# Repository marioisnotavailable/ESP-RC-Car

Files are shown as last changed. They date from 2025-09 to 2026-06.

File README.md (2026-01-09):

# ESP-RC-Car

A self-engineered, open-source drift car powered by an ESP32-S3 microcontroller, designed for a school project. This project integrates robust battery management features, a high-performance mini brushless motor, and a custom phone app controller.

---

## Features

- **ESP32-S3 MCU:** Efficient, reliable microcontroller for all car logic and communication
- **USB Power Delivery & Battery Management:**  
  - Includes Battery Management System (BMS), charging IC, and balancing ICs for battery protection and health
- **Mini1410 2500kv Motor:**  
  - Driven by DRV8323SRTAR motor driver
- **Custom Controller App:**  
  - Written in Flutter, communicates with the car via WebSocket
  - Source code and Android/iOS builds in [`App/final_build`](./App/final_build)
- **PCB Design:**  
  - Schematics and PCB layout created in Altium, available in the repo
- **Firmware:**  
  - PlatformIO based, located in the repo

---

## Hardware Requirements

- ESP32-S3 microcontroller
- Mini1410 2500kv brushless motor
- DRV8323SRTAR motor driver
- USB PD hardware (for charging)
- Battery pack with BMS, charging, and balancing ICs
- Chassis (3D print file provided; other car body prints must be purchased separately)
- Additional electronics (as defined in PCB files)

---

## Getting Started

### Clone the Repo

```bash
git clone https://github.com/marioisnotavailable/ESP-RC-Car.git
```

### Firmware

- Code for the ESP32-S3 is organized for PlatformIO.  
- Configure and build per PlatformIO requirements.

### Controller App

- Find source and builds under [`App/final_build`](./App/final_build)
- Flutter-based; can build for Android or iOS as needed

---

## PCB & Schematics

- All Altium files (schematics and board) are included for public use.

---

## 3D Prints

- Chassis STL provided in this repo
- All other 3D printable parts must be purchased

---

## License

Open source; no specific license chosen at this time.

---

## Media

**[Demo Image Placeholder]**  
*Insert image or GIF of assembled car here*  
**[Demo Video Placeholder]**  
*Insert video or link to demonstration here*

---

## Contributing

Pull requests welcome! If you have ideas for improvements or new features, feel free to submit.

---

## Acknowledgments

This project is open to the community—no personal or institutional credits required.

---

```
**Please update this README with build instructions, usage notes, or troubleshooting tips as the project evolves!**
```

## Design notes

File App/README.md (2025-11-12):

# ESP-RC Car Controller

This is the companion Flutter application for the ESP32-based RC car project. It provides a real-time, low-latency interface to control the car's throttle and steering over a WebSocket connection.

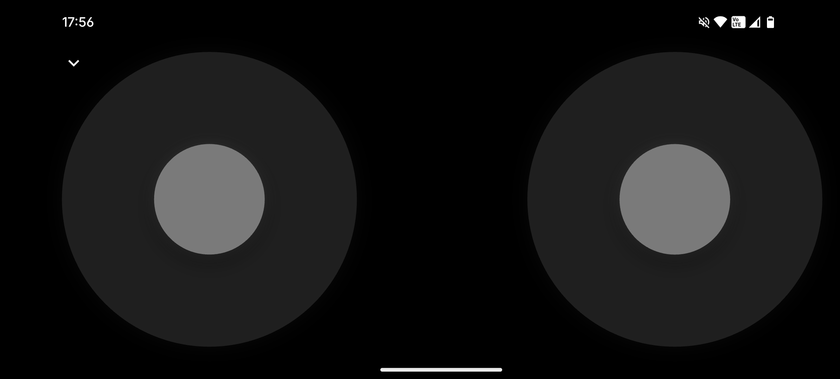
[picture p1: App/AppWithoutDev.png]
App Screenshot


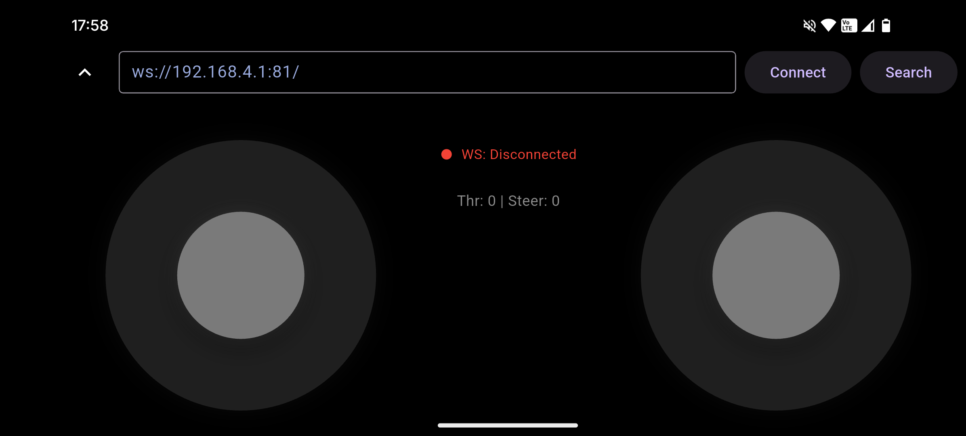
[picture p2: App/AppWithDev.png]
Developer Panel Screenshot


## Features

- **Real-time Control**: Low-latency vehicle control via a WebSocket interface.
- **Dual Control Modes**:
    - Responsive on-screen joysticks for touch-based control.
    - Full support for physical gamepads on both Android and iOS.
- **Automatic Discovery**: The app automatically finds the car on your local network.
    - **UDP Broadcast**: The primary method for quick discovery.
    - **TCP Subnet Scan**: A fallback that scans the entire local network to find the car.
- **Resilient Connectivity**: Automatically reconnects if the connection is lost.
- **Clean UI**: A simple, dark-themed interface that focuses on the driving experience.

## How to Control the Car

### On-Screen Controls
When no gamepad is connected, two virtual joysticks will be visible:

- **Left Joystick (Vertical)**: Controls Throttle (Forward/Reverse).
- **Right Joystick (Horizontal)**: Controls Steering (Left/Right).

### Physical Gamepad
Connect a standard Bluetooth or USB gamepad to your phone for a more tactile experience. The app will automatically detect it.

- **Left Stick (X-Axis)**: Steering
- **Right Trigger (R2/RT)**: Throttle (Forward)
- **Left Trigger (L2/LT)**: Brake / Reverse

## Connection Methods

The app is designed to connect to the ESP32 with minimal effort. It tries the following methods in order:

1.  **UDP Discovery**: On startup, the app sends a broadcast message over the network. The ESP32 is expected to respond with its IP address.
2.  **TCP Scan**: If UDP discovery fails, the app identifies your phone's local subnet (e.g., `192.168.1.0/24`) and scans every host on that network to find the car's WebSocket port.
3.  **Default Fallback**: If both discovery methods fail, it attempts to connect to `ws://192.168.4.1:81/`. This is the default address for when the ESP32 is running in its own Wi-Fi Access Point (AP) mode.
4.  **Manual Connection**: You can tap the "expand" icon at the top of the screen to open the developer panel, where you can manually enter a WebSocket URL and connect.

## Technology Stack

- **Framework**: Flutter
- **Connectivity**: `dart:io` for WebSockets, UDP Sockets, and TCP Sockets.
- **State Management**: `provider` with `ChangeNotifier`.
- **Native Integration**:
    - **Android (Kotlin)**: Uses `InputManager` to listen for native gamepad events.
    - **iOS (Swift)**: Uses the `GameController` framework to listen for native gamepad events.

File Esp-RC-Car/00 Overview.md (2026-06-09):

---
tags: [moc, esp-rc-car, diplomarbeit]
---

# ESP-RC-Car

Diplomarbeitsprojekt **HTL St. Pölten**, 4BHELS — Mario Haunold & Leon Dillinger.
Ferngesteuertes Elektrofahrzeug mit eigenentwickelter Platine, BLDC-Antrieb über DRV8323S, WiFi-WebSocket-Steuerung über eine Flutter-App und vollständigem Energiemanagement (USB-PD-Laden, 2S-LiPo, Zellbalancer).

## Kontext

- Schuljahr 2025/26 — Planung Sept. 2025, erste Platine bestellt/getestet Dez. 2025, überarbeitete Platine ab März 2026
- Abgabedatum 29.5.2026, Lehrer RZEP
- Eigene Mehrlagen-PCB in Altium Designer, eigene Firmware (PlatformIO/ESP-IDF), eigene App (Flutter/Dart)

## Inspiration

Mechanische Grundlage: Open-Source-Projekt [Build a 3D Printed Arduino RC Drift Car](https://www.instructables.com/Build-a-3D-Printed-Arduino-RC-Drift-Car-With-Smoke/) (Instructables). Übernommen: Allrad-Antriebsstrang mit Differential, Radaufhängung, Servo-Lenkmechanik. Neu entwickelt: das gesamte Chassis (an die eigene Platine angepasst) sowie die komplette Elektronik und Steuersoftware.

## Themen-Notizen

- [[Firmware Overview|Firmware]] — ESP32-S3, ESP-IDF, FreeRTOS-Tasks, BLDC-Kommutierung, Safe Mode
- [[PCB|Hardware / PCB]] — Schaltplan, ICs, MOSFETs, erste/zweite Platinen-Version
- [[Motor & Treiber]] — Mini1410 BLDC + DRV8323S Gate-Treiber
- [[App Overview|Flutter App]] — WebSocket-Steuerung, Joystick, Gamepad, Discovery, Batterieanzeige
- [[3D-Druck]] — Chassis-Iterationen, Restmechanik aus Referenzprojekt

## Kern-Stack

| Bereich | Technologie |
|---|---|
| MCU | ESP32-S3-WROOM-1-N8 (8 MB Flash) |
| Firmware | C++ / PlatformIO / ESP-IDF |
| Motor | BLDC Mini1410 2500 kV |
| Gate-Treiber | DRV8323SRTAR (SPI, 6 PWM) |
| Leistungsstufe | 6× IPD047N03LF2 (30 V N-Ch) |
| Energie | USB-PD via STUSB4500 + MP2615 Lader + 2S LiPo |
| Schutz | S-82B2 (Primärschutz) + BQ29200 (Balancing) |
| Power-Pfad | TPS2121 Power-Mux + LMR51430 3,3 V Buck |
| App | Flutter (Android/iOS/Windows), WebSocket + UDP-Discovery |

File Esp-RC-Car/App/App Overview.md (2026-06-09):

---
tags: [app, flutter, dart, esp-rc-car]
---

# Flutter App — Übersicht

Cross-platform Controller-App für das [[ESP-RC-Car]], geschrieben in **Flutter/Dart**. Steuert das Fahrzeug per WiFi-WebSocket in Echtzeit, zeigt die Batteriespannung an und erlaubt die Server-Suche im lokalen WLAN.

## Plattformen

- Android (Release-APK: `App/final_build/EspRCCar.apk`)
- iOS (CocoaPods-Integration, IPA: `App/final_build/EspRCCar.ipa`)
- Windows (nativer Gamepad-Support via `gamepad_channel.cpp`)
- macOS, Linux, Web (Flutter-Standard)

## Architektur

```
main.dart
├── MultiProvider
│   ├── ConnectionService    ← WebSocket + UDP/TCP-Discovery
│   └── ControllerService    ← Gamepad/Joystick → Steuerbefehle
└── RCCarApp
    ├── ui/dev_panel.dart      ← DevPanel (Diagnose + Update)
    ├── ui/gamepad_status.dart ← Gamepad-Verbindungsanzeige
    └── widgets/joystick.dart  ← Touch-Joystick-Widget

update_service.dart            ← GitHub-Release Self-Update (Android)
```

State-Management über das `provider`-Package; sowohl `ConnectionService` als auch `ControllerService` sind `ChangeNotifier`.

## UI-Ausrichtung

App startet immer im **Landscape-Modus**:

```dart
SystemChrome.setPreferredOrientations([
  DeviceOrientation.landscapeLeft,
  DeviceOrientation.landscapeRight,
])
```

## Steuerung

- Virtueller Joystick mit konfigurierbarer Empfindlichkeit / Totzone und Skalierungsfunktion (gegen Zittern)
- Physischer Gamepad-Controller als Alternative (Bluetooth/USB)
- 50 Hz Sendeloop mit EMA-Tiefpassfilterung
- Übertragung über WebSocket: Throttle/Steer/Flags als JSON oder Rohwerte

## Server-Discovery

1. Standardmäßig **UDP-Broadcast-Discovery** auf dem lokalen Netz → Fahrzeug antwortet mit seinem WebSocket-Endpunkt
2. Fallback: **TCP-Subnet-Scan** falls UDP blockiert wird
3. Zuletzt verwendete URL wird in `SharedPreferences` persistiert (Standard im Soft-AP-Modus: `ws://192.168.4.1:81/`)
4. Manuelle URL-Eingabe im DevPanel

## Batterieanzeige

Echtzeit-Anzeige der 2S-LiPo-Spannung mit prozentualer Restkapazität, Farbcode und Icon. Der Wert kommt aus dem `batt_queue` der Firmware und wird über WebSocket gepusht.

## DevPanel

- Verbindungsstatus, Latenz, empfangene Sensordaten
- Manuelle WebSocket-URL
- ⟳-Update-Button (nur Android)

## In-App-Update (Android)

- `update_service.dart` liest `releases/latest` über die GitHub-Releases-API, vergleicht mit der installierten Version (`package_info_plus`)
- Bei neuer Version: APK herunterladen (`http` + `path_provider`), Installer öffnen (`open_filex`)
- Voraussetzung: alle Releases mit demselben Signing-Key
- App-Version kommt im CI aus dem Release-Tag (`flutter build --build-name`)

## Bibliotheken

| Paket | Zweck |
|---|---|
| `web_socket_channel` | WebSocket zur ESP32-Firmware |
| `flutter_joystick` | virtueller Joystick |
| `gamepad` | physischer Controller |
| `shared_preferences` | Server-URL persistieren |
| `provider` | State-Management |
| `package_info_plus` / `http` / `path_provider` / `open_filex` | Self-Update |

## Module

- [[ConnectionService]] — WebSocket + UDP/TCP-Discovery
- [[ControllerService]] — Gamepad/Joystick-Steuerlogik
- [[UpdateService]] — GitHub-Release Self-Update (Android)

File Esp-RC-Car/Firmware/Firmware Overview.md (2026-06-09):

---
tags: [firmware, esp32, espidf, freertos, esp-rc-car]
---

# Firmware Overview

PlatformIO-Projekt auf **ESP-IDF**, Ziel: **ESP32-S3-WROOM-1-N8** (8 MB Flash). Hauptaufgaben: BLDC-Motoransteuerung, WiFi/WebSocket-Server, Servo-Lenkung, ADC-Batteriemessung, USB-PD-Konfiguration, OTA-Update, Crash-Recovery / Safe Mode.

Siehe auch: [[ESP-RC-Car|Projekt-Übersicht]], [[PCB]], [[Motor & Treiber]].

## Build-Environments

| Environment | Beschreibung |
|---|---|
| `espidf` | Hauptfirmware (USB Serial Upload) |
| `espidf_ota` | OTA-Upload via `esp-rc-car.local` |
| `espidf_factory` | Factory-Recovery-Firmware |

OTA-Passwort: `esprccar`.

## Projektstruktur

```
Code/
├── platformio.ini       framework = espidf
├── sdkconfig.defaults   ESP-IDF Konfiguration
├── partitions.csv       Flash-Partitionierung
├── src/main.c           app_main: Init + 4 Tasks spawnen
└── components/
    ├── rc_common/       Shared: Cmd, Queues, EventGroup, Pins
    ├── rc_motor/        motor_task + DRV8323 SPI
    ├── rc_comms/        comms_task: WiFi, WebSocket, UDP
    ├── rc_system/       system_task: ADC, NVS, Recovery, Servo
    └── rc_bg/           bg_task: FOTA, Serial Console
```

## Flash & Partitionen

- 16 MB QIO-OPI Flash
- Filesystem: **LittleFS** (Partition-Label `littlefs`, Mount `/littlefs`)
- Partitions: `partitions.csv` (custom, inkl. zwei OTA-App-Slots + Factory)

## sdkconfig Highlights

- CPU: 240 MHz
- FreeRTOS: 1000 Hz Tick
- Task-Watchdog: 10 s Timeout
- WebSocket-Support: aktiviert
- SPIRAM: aktiv im **OCT-Modus** (Board hat OPI-PSRAM)
- OTA-Rollback: `CONFIG_BOOTLOADER_APP_ROLLBACK_ENABLE=y`

## FreeRTOS Task-Architektur

```
app_main()
  nvs_flash_init() → esp_netif_init() → rc_common_init()
  rc_recovery_check() → rc_settings_load()
  │
  ├── motor_task   Prio 10  4 KB  BLDC Kommutierung + DRV8323
  ├── comms_task   Prio 7   8 KB  WiFi + WebSocket + UDP
  ├── system_task  Prio 5   6 KB  ADC + Settings + Recovery + Servo
  └── bg_task      Prio 2   6 KB  FOTA + Serial Console
```

### Inter-Task-Kommunikation

```
comms_task  → xQueueOverwrite(cmd_queue)  → motor_task
system_task → xQueueOverwrite(batt_queue) → comms_task (broadcast)

rc_events (EventGroup):
  BIT0: WIFI_CONNECTED_BIT
  BIT1: SAFE_MODE_BIT     → motor_task suspendiert sich
  BIT2: MOTOR_FAULT_BIT   → DRV8323 Fault erkannt
```

## WiFi & Konfiguration

Beim Boot versucht der ESP32-S3 sich mit einem in NVS gespeicherten WLAN zu verbinden. Wird kein bekanntes Netzwerk gefunden, startet er einen **Soft-AP** mit eingebettetem Webserver, über den per Browser SSID/Passwort hinterlegt werden können. Nach Neustart verbindet sich der MCU mit dem konfigurierten Netzwerk und betreibt dort den WebSocket-Server für die Steuerung. Der AP dient ausschließlich der Konfiguration — die Fahrzeugsteuerung läuft nur im gemeinsamen WLAN.

Discovery: Der ESP32-S3 sendet einen UDP-Beacon mit seinem WebSocket-Endpunkt; die App findet ihn darüber automatisch, als Fallback per TCP-Subnet-Scan.

## BLDC-Kommutierung

- Gate-Treiber: **DRV8323SRTAR** (TI) über dedizierten SPI-Bus
- 6 PWM-Kanäle via **LEDC** für die 3-Phasen-Vollbrücke (INH_A/B/C high-side, INL_A/B/C low-side)
- 6-Step-Trapezoid-Kommutierung mit Ramp-Up
- Fault-Erkennung über `nFAULT`-Pin → `MOTOR_FAULT_BIT`
- Phasenstromerfassung über drei Low-Side-Shunts mit den Stromsense-Ausgängen SOA/SOB/SOC

## Servo-Lenkung

Servo wird über LEDC-PWM angesteuert (~50 Hz, 1–2 ms Pulsbreite, Mitte 1,5 ms).

## Batterie & USB-PD

- `rc_battery`: 2S-LiPo-Spannung via ADC-Spannungsteiler an GPIO13/GPIO14 (`adc_oneshot`), Wert wird über WebSocket an verbundene App-Clients gepusht
- `rc_usbpd` (in `rc_system`): I²C-Konfiguration des **STUSB4500** (Sink-Profil 12 V), `ALERT` an GPIO8, I²C an GPIO9/GPIO10

## OTA

`rc_ota` nutzt `esp_https_ota` für signierte Firmware-Updates ohne USB-Kabel; Rollback ist im Bootloader aktiviert.

## Safe Mode / Recovery

- `rc_recovery_check()` liest einen NVS-Crash-Counter beim Boot
- Häufen sich Crashes, wird `SAFE_MODE_BIT` gesetzt → `motor_task` suspendiert sich, Fahrzeug bleibt steuerlos aber im Netz erreichbar
- Stabilisiert sich die Firmware, ruft das System `rc_recovery_mark_stable()` und der Counter wird zurückgesetzt

## Pin-Map (Auszug)

| Funktion | GPIO |
|---|---|
| DRV8323 SPI (SCLK / MOSI / MISO / SS) | 5 / 6 / 7 / 16 |
| DRV8323 nFAULT | 39 |
| DRV8323 CAL | 28 |
| INH_A / INH_B / INH_C | 18 / 3 / 10 |
| INL_A / INL_B / INL_C | 8 / 9 / 11 |
| I²C SDA / SCL (STUSB4500, BQ29200) | 21 / 47 |
| STUSB4500 ALERT | 8 |
| Batt ADC Zellen | 13 / 14 |
| LMR51430 Enable | 3 |

## Module

- [[rc_motor]] — BLDC + DRV8323S
- [[rc_websocket]] — WebSocket-Server (esp_http_server)
- [[rc_network]] — WiFi (esp_wifi) + UDP-Discovery
- [[rc_battery]] — Batterie-ADC
- [[rc_ota]] — FOTA (esp_https_ota)
- [[rc_recovery]] — Crash / Safe Mode
- [[rc_steering]] — Servo-LEDC
- [[rc_settings]] — NVS Settings
- [[rc_pins]] — Pin-Definitionen
- [[drv8323]] — Gate-Driver-SPI-Treiber

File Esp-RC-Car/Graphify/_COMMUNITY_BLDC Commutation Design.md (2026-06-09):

---
type: community
cohesion: 0.50
members: 4
---

# BLDC Commutation Design

**Cohesion:** 0.50 - moderately connected
**Members:** 4 nodes

## Members
- [[6-Step Trapezoidal Commutation]] - concept - Esp-RC-Car/Graphify/6-Step Trapezoidal Commutation.md
- [[BLDC Motor Test Spin Design]] - document - Esp-RC-Car/Graphify/6-Step Trapezoidal Commutation.md
- [[Motor Driver Rewrite Design Spec]] - document - Esp-RC-Car/Graphify/6-Step Trapezoidal Commutation.md
- [[rc_motor_apply_phase]] - code - Esp-RC-Car/Graphify/6-Step Trapezoidal Commutation.md

## Live Query (requires Dataview plugin)

```dataview
TABLE source_file, type FROM #community/BLDC_Commutation_Design
SORT file.name ASC
```

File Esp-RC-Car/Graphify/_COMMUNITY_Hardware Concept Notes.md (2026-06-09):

---
type: community
cohesion: 0.17
members: 12
---

# Hardware Concept Notes

**Cohesion:** 0.17 - loosely connected
**Members:** 12 nodes

## Members
- [[Altium PCB Schematics & Layout]] - document - Esp-RC-Car/Graphify/ESP-RC-Car Project README.md
- [[Battery Management Subsystem (BMS + Charging + Balancing)]] - concept - Esp-RC-Car/Graphify/ESP-RC-Car Project README.md
- [[DRV8323SRTAR Motor Driver]] - concept - Esp-RC-Car/Graphify/ESP-RC-Car Project README.md
- [[ESP-RC Car Controller App README]] - document - Esp-RC-Car/Graphify/ESP-RC-Car Project README.md
- [[ESP-RC-Car Project README]] - document - Esp-RC-Car/Graphify/ESP-RC-Car Project README.md
- [[Manual WebSocket URL Connection (Dev Panel)]] - concept - Esp-RC-Car/Graphify/Manual WebSocket URL Connection (Dev Panel).md
- [[Mini1410 2500kv Brushless Motor]] - concept - Esp-RC-Car/Graphify/ESP-RC-Car Project README.md
- [[PlatformIO Firmware Stack]] - concept - Esp-RC-Car/Graphify/ESP-RC-Car Project README.md
- [[TCP Subnet Scan Discovery Fallback]] - concept - Esp-RC-Car/Graphify/UDP Broadcast Discovery.md
- [[UDP Broadcast Discovery]] - concept - Esp-RC-Car/Graphify/UDP Broadcast Discovery.md
- [[WebSocket Phone-Car Communication]] - concept - Esp-RC-Car/Graphify/ESP-RC-Car Project README.md
- [[network_info_plus dependency]] - concept - Esp-RC-Car/Graphify/UDP Broadcast Discovery.md

## Live Query (requires Dataview plugin)

```dataview
TABLE source_file, type FROM #community/Hardware_Concept_Notes
SORT file.name ASC
```

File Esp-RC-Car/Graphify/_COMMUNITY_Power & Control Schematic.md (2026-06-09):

---
type: community
cohesion: 0.21
members: 12
---

# Power & Control Schematic

**Cohesion:** 0.21 - loosely connected
**Members:** 12 nodes

## Members
- [[Battery info line (mb Info ueber Batterie)]] - concept - Esp-RC-Car/Graphify/ESP (ESP32 microcontroller - main controller).md
- [[Buck converter (5V12V on I2C line)]] - concept - Esp-RC-Car/Graphify/Buck converter (steps down voltage, labeled 5V12V on I2C line).md
- [[ESC (Electronic Speed Controller for motor)]] - concept - Esp-RC-Car/Graphify/ESP (ESP32 microcontroller - main controller).md
- [[ESP (ESP32 microcontroller - main controller)]] - concept - Esp-RC-Car/Graphify/ESP (ESP32 microcontroller - main controller).md
- [[I2C bus (5V12V rail)]] - concept - Esp-RC-Car/Graphify/Buck converter (steps down voltage, labeled 5V12V on I2C line).md
- [[Lade IC (battery charger IC)]] - concept - Esp-RC-Car/Graphify/USB-C input port (chargingpower input).md
- [[MUX (power source multiplexer)]] - concept - Esp-RC-Car/Graphify/Buck converter (steps down voltage, labeled 5V12V on I2C line).md
- [[PWM signal line to servo]] - concept - Esp-RC-Car/Graphify/ESP (ESP32 microcontroller - main controller).md
- [[PWMSPI signal line to ESC]] - concept - Esp-RC-Car/Graphify/ESP (ESP32 microcontroller - main controller).md
- [[SchaltungSkizze - Hand-drawn circuit sketch]] - image - Esp-RC-Car/Graphify/Buck converter (steps down voltage, labeled 5V12V on I2C line).md
- [[Servo (steering servo, driven by PWM)]] - concept - Esp-RC-Car/Graphify/ESP (ESP32 microcontroller - main controller).md
- [[USB-C input port (chargingpower input)]] - concept - Esp-RC-Car/Graphify/USB-C input port (chargingpower input).md

## Live Query (requires Dataview plugin)

```dataview
TABLE source_file, type FROM #community/Power__Control_Schematic
SORT file.name ASC
```

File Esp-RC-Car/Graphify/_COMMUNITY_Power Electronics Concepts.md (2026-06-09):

---
type: community
cohesion: 0.40
members: 5
---

# Power Electronics Concepts

**Cohesion:** 0.40 - moderately connected
**Members:** 5 nodes

## Members
- [[ESC (Electronic Speed Controller)]] - concept - Esp-RC-Car/Graphify/FET (Power Switch  MOSFET).md
- [[FET (Power Switch  MOSFET)]] - concept - Esp-RC-Car/Graphify/FET (Power Switch  MOSFET).md
- [[LiPo Battery]] - concept - Esp-RC-Car/Graphify/FET (Power Switch  MOSFET).md
- [[Power System Diagram (hand-drawn)]] - image - Esp-RC-Car/Graphify/FET (Power Switch  MOSFET).md
- [[VR (Voltage Regulator)]] - concept - Esp-RC-Car/Graphify/FET (Power Switch  MOSFET).md

## Live Query (requires Dataview plugin)

```dataview
TABLE source_file, type FROM #community/Power_Electronics_Concepts
SORT file.name ASC
```

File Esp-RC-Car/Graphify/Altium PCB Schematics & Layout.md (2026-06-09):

---
source_file: "Esp-RC-Car/Graphify/ESP-RC-Car Project README.md"
type: "document"
community: "Hardware Concept Notes"
tags:
  - graphify/document
  - graphify/EXTRACTED
  - community/Hardware_Concept_Notes
---

# Altium PCB Schematics & Layout

## Connections
- [[ESP-RC-Car Project README]] - `references` [EXTRACTED]

#graphify/document #graphify/EXTRACTED #community/Hardware_Concept_Notes

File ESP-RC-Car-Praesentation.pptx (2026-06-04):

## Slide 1

ESP-RC-CAR

Schulprojekt · 4BHELS

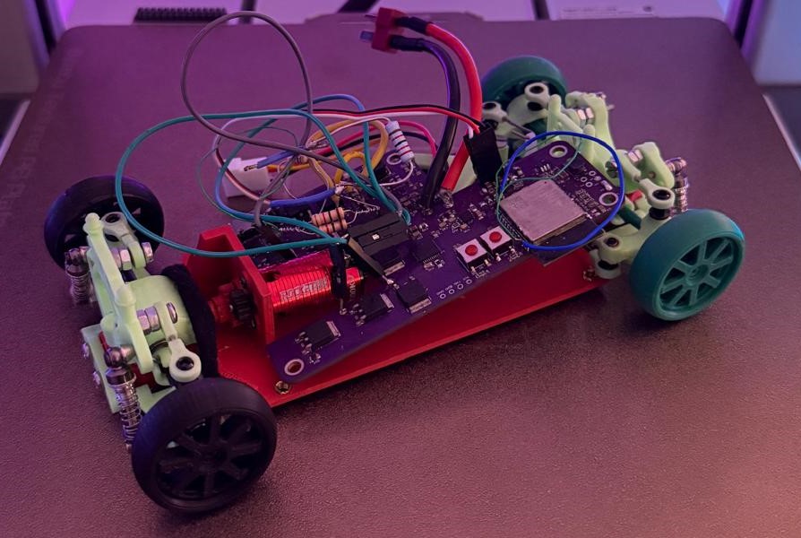
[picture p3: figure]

Selbst entwickeltes Drift-Car

gesteuert via Flutter-App über WiFi

Teil 1 — Hardware & App

Teil 2 — Firmware & Mechanik

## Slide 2

TEIL 1 — ÜBERBLICK

Systemarchitektur

Vier Schichten — von der App bis zum Motor

Android · iOS · Windows · Web · Touch-Joystick · Gamepad

WiFi · WebSocket ws://[IP]:80 · UDP Discovery :49352

Flutter App

ESP32-S3 — FreeRTOS / ESP-IDF 6.0

motor_task

comms_task

system_task

bg_task

PWM

DRV8323S Gate Driver
3-Phasen Halbbrücke

Servo-PWM

S0009M Lenkservo 9g
50 Hz · 1000–2000 µs

Mini1410 BLDC Motor 2500 kV

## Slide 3

TEIL 1 — HARDWARE

PCB — Stromversorgung

Altium Designer · Custom 2-Lagen Board

USB-C PD
12 V

Lade IC
12V → CC/CV

lädt

MUX
Quellenauswahl

Buck Conv.
→ 3.3 V

2S LiPo 7.4 V

BMS IC — Balancing & Schutz

DRV8323S
+ MOSFETs

ESP32-S3
3.3 V

BLDC Motor
direkt

Motorpfad (Batteriespannung direkt, ohne Konvertierung)

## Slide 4

TEIL 1 — APP

Flutter App

Cross-Platform Controller — Android · iOS · Windows · Web

Android

iOS

Windows

Web


Steuerung

▸ Linker Joystick → Gas / Bremse

▸ Rechter Joystick → Lenkung

▸ Gamepad R2/RT = Gas · L2/LT = Rückwärts

Features

▸ Auto-Discovery (UDP · TCP-Scan · AP-Fallback)

▸ Automatischer Reconnect

▸ GitHub Self-Update (Android In-App)

▸ Dark Theme · Developer Panel

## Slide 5

TEIL 1 — APP

Kommunikation: App ↔ ESP32

Verbindungsaufbau · Protokoll · Failsafe

Schritt 1 — Auto-Discovery

UDP Broadcast

App sendet → ESP32 antwortet mit IP

TCP Subnet-Scan

Fallback: scannt Subnetz auf WS-Port

AP-Mode

192.168.4.1 (ESP32 als Access Point)

Schritt 2 — WebSocket ws://[IP]:80/ws

App → ESP32 (50 Hz Steuerbefehl)

{
"throttle": -1000 … +1000,
"steer": -1000 … +1000
}

ESP32 → App (1 × pro Sekunde)

{ "batt": 0 … 100 } // Batterie %

Failsafe: 500 ms kein Paket → Nullbefehl

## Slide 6

TEIL 2

ESP Firmware
& Mechanik

FreeRTOS · 6-Step BLDC · WiFi · 3D-Druck

ESP-IDF 6.0 · PlatformIO · FreeRTOS 1000 Hz

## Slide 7

TEIL 2 — FIRMWARE

FreeRTOS — 4 Tasks

Jeder Task hat eine klare Verantwortung · ESP-IDF 6.0

motor_task

Prio 10 · 4 KB

▸ 6-Step BLDC Kommutierung

▸ DRV8323S SPI + Fault

▸ Safe-Mode → Suspend

comms_task

Prio 7 · 8 KB

▸ WiFi esp_wifi

▸ WebSocket Port 80

▸ UDP Discovery

system_task

Prio 5 · 6 KB

▸ ADC Batterie-Monitor

▸ NVS Einstellungen

▸ Crash-Recovery

bg_task

Prio 2 · 6 KB

▸ GitHub FOTA

▸ Serial Console

▸ OTA Rollback Guard

comms_task → cmd_queue → motor_task system_task → batt_queue → comms_task → WebSocket broadcast

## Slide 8

TEIL 2 — MOTOR

Motor & Gate Driver

DRV8323SRTAR · 6-Step Trapez · 20 kHz PWM · Soft-Start

DRV8323SRTAR

6-Step Kommutierung

Soft-Start

▸ Duty-Rampe

▸ 50 ms → 5 ms

▸ Reset bei Richtung

Gehäuse

VQFN-40

INH_A

INL_A

INH_B

INL_B

INH_C

INL_C

Ø

Spannung

6 – 60 V

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
A+B−

A+C−

Interface

SPI · 5 Register

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
B+C−

B+A−

Schutz

OCP · VDS · Temp

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
C+A−

C+B−

Fault

▸ nFAULT → off

▸ 500 ms Pause

▸ Register reset

▸ SAFE_MODE

CSA Gain

10× · LS-Shunt

Motorphasen-Zustände:

High-Side aktiv (moduliert)

Low-Side aktiv (LOW)

Float (keine Ansteuerung)

nFAULT

aktiv LOW

PWM

L

—

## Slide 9

TEIL 2 — FIRMWARE

Netzwerk & OTA-Updates

WiFi · WebSocket · GitHub FOTA · PlatformIO OTA Upload

Netzwerk

WiFi

SSID/Passwort in NVS · Auto-Reconnect

WebSocket

esp_http_server Port 80 · Route /ws

UDP Discovery

Port 49352 · eigener Sub-Task Prio 4

AP-Mode

Fallback wenn kein Netzwerk

Failsafe

500 ms kein Paket → Motor-Stopp

GitHub FOTA — automatisch

▸ bg_task prüft GitHub Releases (alle 5 min)

▸ esp_https_ota → neuen Partition-Slot flashen

▸ Neustart · Auto-Rollback bei Fehler

OTA Upload — manuell (PlatformIO)

▸ Upload-Ziel: esp-rc-car.local

▸ Passwort-gesichert

▸ Umgebung: espidf_ota (platformio.ini)

NVS: SSID/Passwort · OTA-Intervall · Batterie-Schwellen · Servo-Gain · Failsafe-Zeit · max_throttle_pct …

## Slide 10

TEIL 2 — MECHANIK

Chassis & Mechanik

3D-Druck · Blender · PLA · S0009M Lenkservo

3D-Druck

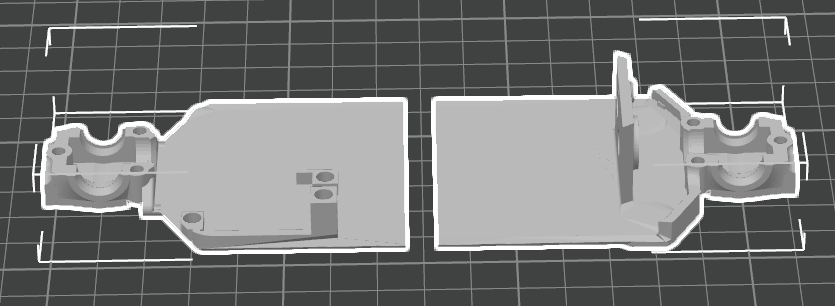
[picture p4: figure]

[ Chassi V8 Render ]

[ verbindung v1 Render ]

Hauptkörper

Chassi V8.stl

Verbinder

Software

verbindung v1.stl

Blender

Material

PLA

Iterationen

V1 → V8

Lenkservo

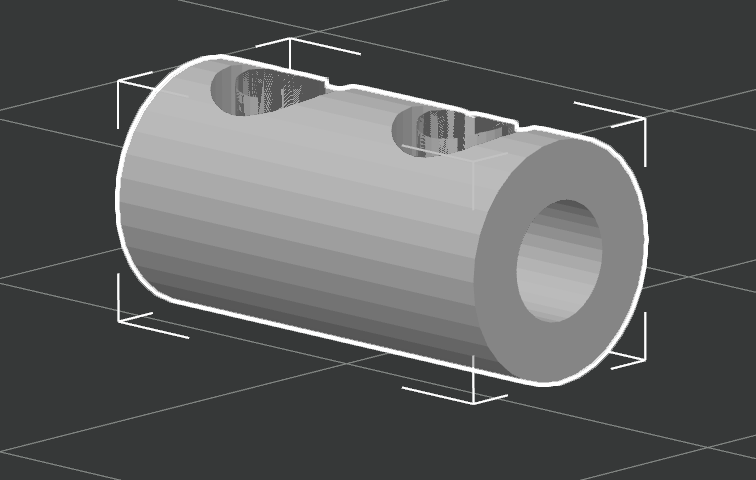
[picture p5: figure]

Modell

S0009M 9g Micro Servo

Signal

Filter

50 Hz · 1000–2000 µs

IIR · Gain einstellbar

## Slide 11

ESP-RC-Car

Schulprojekt 4BHELS — Zusammenfassung

Hardware

ESP32-S3 · DRV8323
2S LiPo · PCB

App

Flutter
Android/iOS/Win/Web

Firmware

FreeRTOS · ESP-IDF 6.0
6-Step BLDC

Mechanik

Chassi V8 · Blender
Servo S0009M

Demo — Live Vorführung

github.com/marioisnotavailable/ESP-RC-Car

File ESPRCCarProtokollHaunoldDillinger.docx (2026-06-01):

PROTOKOLL zum Projekt Esp RC Car
Gruppe / Klasse | Protokollführer | Unterschrift:
4BHELS | Leon Dillinger
Übungs- / Abgabedatum | Protokollführer | Unterschrift:
29.5.2026 | Mario Haunold
Lehrer | Mitarbeiter | Unterschrift:
RZEP
Note: | Mitarbeiter | Unterschrift:

VERWENDETE GERÄTE:

# 1 Aufgabenstellung

Im Rahmen des Projekts ESP-RC-Car sollte ein ferngesteuertes Elektrofahrzeug von Grund auf entwickelt werden. Kernstück ist ein ESP32-S3-Mikrocontroller auf einer selbst entworfenen Platine (PCB), der einen bürstenlosen Gleichstrommotor (BLDC) über einen DRV8323S-Gate-Treiber und eine 3-Phasen-MOSFET-Vollbrücke ansteuert. Die Steuerung erfolgt drahtlos über WiFi mittels einer eigens entwickelten Flutter-Smartphone-App, die einen virtuellen Joystick und Gamepad-Unterstützung bietet. Das Fahrgestell wurde in mehreren Iterationen selbst in 3D gedruckt. Zusätzlich umfasst das Projekt ein vollständiges Energiemanagement-System: USB-Power-Delivery (USB-PD) zum Laden, ein dediziertes Lademanagement-IC, einen 2S-LiPo-Schutzschaltkreis mit Zell-Balancer sowie eine Echtzeit-Batteriezustandsanzeige in der App.

## 1.1 Inspiration und mechanische Grundlage

Als Ausgangspunkt für das mechanische Konzept diente das Open-Source-Projekt „Build a 3D Printed Arduino RC Drift Car With Smoke Effect!“ von Instructables (https://www.instructables.com/Build-a-3D-Printed-Arduino-RC-Drift-Car-With-Smoke/). Das dort vorgestellte Fahrzeug basiert auf einem vollständig 3D-gedruckten Chassis mit Allradantrieb, einer Differenzialsperre sowie einem Servo-gesteuerten Lenksystem. Die Mechanik – insbesondere die Grundstruktur des Fahrgestells, die Radaufhängung, der Antriebsstrang mit Differentiale sowie die Servo-Lenkmechanik – wurde für das ESP-RC-Car übernommen und als Ausgangsbasis für eigene Anpassungen und Weiterentwicklungen genutzt.

Der wesentliche Eigenanteil des ESP-RC-Car-Projekts liegt in der vollständigen Neuentwicklung der Elektronik: Anstelle eines einfachen Arduino-Mikrocontrollers und eines handelsüblichen ESCs wurde eine eigene mehrlagige Platine mit ESP32-S3, selbst implementierter BLDC-Regelung über den DRV8323SRTAR, USB-PD-Lademanagement und 2S-LiPo-Schutzbeschaltung entwickelt. Auch die Steuerung wurde von Grund auf neu konzipiert – als Flutter-App mit WebSocket-Kommunikation anstelle einer klassischen RC-Fernbedienung.

# 2 Theoretische Grundlagen

## 2.1 ESP32-Mikrocontroller

Der ESP32-S3 ist ein 32-Bit-Dual-Core-Mikrocontroller (Xtensa LX7, bis 240 MHz) der Firma Espressif Systems mit integriertem WLAN (802.11 b/g/n) und Bluetooth 5 (LE). Im Projekt wird das Modul ESP32-S3-WROOM-1-N8 mit 8 MB Flash eingesetzt. Es verfügt über zahlreiche GPIO-Pins für digitale und analoge Ein-/Ausgaben, SPI-, I²C- und UART-Schnittstellen sowie einen integrierten LEDC-PWM-Controller mit bis zu 8 unabhängigen Kanälen. Im vorliegenden Projekt übernimmt der ESP32-S3 alle zentralen Aufgaben: BLDC-Motoransteuerung via SPI und PWM, WiFi-Kommunikation mit der Smartphone-App, Batterieüberwachung (ADC) sowie Steuerung des USB-PD- und Lademanagement-ICs über I²C.

## 2.2 WiFi-WebSocket-Kommunikation

Die Kommunikation zwischen Smartphone-App und Fahrzeug erfolgt über WiFi (IEEE 802.11 b/g/n) mittels WebSocket-Protokoll (RFC 6455). Der ESP32-S3 verbindet sich beim Start mit einem konfigurierten WLAN-Netzwerk und betreibt dort einen WebSocket-Server. Wird kein gespeichertes Netzwerk gefunden, öffnet der ESP32-S3 automatisch einen Access Point (Soft-AP), über den ein Gerät (z.B. Smartphone) die WLAN-Konfiguration über einen integrierten Webserver vornehmen kann (SSID und Passwort hinterlegen). Nach einem Neustart verbindet sich der ESP32-S3 mit dem konfigurierten Netzwerk. Der AP dient ausschließlich der Konfiguration – die Steuerung des Fahrzeugs erfolgt nur im gemeinsamen WLAN. Sobald App und ESP32-S3 im selben Netzwerk sind, kann die Flutter-App über den Search-Button nach dem Fahrzeug suchen: zunächst per UDP-Beacon (der ESP32-S3 broadcastet seinen WebSocket-Endpunkt ins Netzwerk), als Fallback über eine manuelle TCP-Port-Suche. Die zuletzt verwendete Server-URL wird über SharedPreferences gespeichert. WebSocket bietet dabei gegenüber einfachen HTTP-Anfragen eine dauerhafte Vollduplex-Verbindung mit minimaler Latenz für die Übertragung von Steuerbefehlen (Joystick-X/Y, Gamepad-Tasten) in Echtzeit.

## 2.3 BLDC-Motor und DRV8323S-Gate-Treiber

Das Fahrzeug wird von einem bürstenlosen Gleichstrommotor (BLDC, Mini1410 2500 kV) angetrieben. Im Gegensatz zu bürstenbehäafteten DC-Motoren besitzen BLDC-Motoren keinen mechanischen Kommutator; die Kommutierung erfolgt elektronisch durch wechselweises Schalten der drei Motorphasen. Dafür kommt der DRV8323SRTAR (Texas Instruments) zum Einsatz – ein 3-Phasen-Gate-Treiber-IC, der über SPI vom ESP32-S3 konfiguriert wird und sechs PWM-Eingangssignale (INH_A/B/C, INL_A/B/C) für die High- und Low-Side-Schalter empfängt. Die eigentliche Leistungsstufe bilden sechs N-Kanal-MOSFETs (IPD047N03LF2SATMA1, 30 V / 120 A) als 3-Phasen-Vollbrücke. Drei Shunt-Widerstände auf den Low-Side-Pfaden ermöglichen die Phasenstrommessung; ein integrierter Fault-Ausgang (nFAULT) signalisiert Überstrom- oder Übertemperaturereignisse an den ESP32-S3. Der DRV8323SRTAR kommuniziert über einen dedizierten SPI-Bus (SCLK, MOSI_DRV, MISO_DRV, SS) mit dem ESP32-S3 und stellt außerdem Stromsense-Ausgänge (SOA, SOB, SOC) sowie Bootstrapping-Leitungen (SHA/GHA, SHB/GHB, SHC/GHC) für die Gate-Treiber-Versorgung bereit. Die Kalibrierung des integrierten Stromverstärkers erfolgt über den CAL-Pin (GPIO28 des ESP32-S3).

## 2.4 MP2615AGQ-Z – Synchroner Buck-Boost-Ladecontroller (IC2)

Der MP2615AGQ-Z von Monolithic Power Systems (MPS) ist ein synchroner Buck-Boost-Ladecontroller für 2S-LiPo-Akkus (IC2). Er lädt den Akku über den von STUSB4500 ausgeregelten VBUS-Pfad und stellt einen Ladestrom bereit, der über externe Widerstände einstellbar ist. Über den CHARGE-Pin kann der Ladevorgang vom ESP32-S3 ein- und ausgeschaltet werden. Die Batteriezustandsanzeige in der App basiert auf einer direkten ADC-Messung der Akkuspannung am ESP32-S3 über einen Spannungsteiler. Intern integriert der IC MOSFET-Schalter und eine Regelschleife, die eine konstante Spannung / konstanten Strom (CC/CV) realisiert. Das Chip-Gehäuse ist ein 16-poliges QFN (1 mm Höhe).

## 2.5 S-82B2AAA-A8T2U – Primärer 2S-Batterieschutz (IC3)

Der S-82B2AAA-A8T2U von ABLIC Inc. (IC3) übernimmt den primären Überspannungs- und Unterspannungsschutz für den 2S-LiPo-Akku. Er überwacht beide Zellen (VBAT+ und VBAT-) separat und schaltet bei Über- oder Unterspannung die Lade- bzw. Entladepfade ab, indem er die externen Schutz-MOSFETs (IC7, BQ29200) ansteuert. Das IC ist im ultrakleinen SOT-23-9-Gehäuse (0,4 mm Höhe) ausgeführt und benötigt nur wenige externe Bauelemente. Die Pins NetIC3_1 bis NetIC3_5 führen zu Filterkondensatoren und den MOSFET-Gate-Steuerleitungen.

## 2.6 TPS2121RUXT – Dual-Eingang-Power-Multiplexer (IC4)

Der TPS2121RUXT von Texas Instruments (IC4) ist ein Dual-Eingang-Power-Multiplexer (Power-Mux), der automatisch zwischen dem USB-PD-Versorgungspfad (VBUS) und dem Akku (VBAT) als Quelle für den Systembus (VSYS) umschaltet. Er priorisiert dabei den USB-Pfad, solange dieser verfügbar ist, und wechselt nahtlos auf den Akku bei abgestecktem USB-Kabel. Der IC ist im 12-poligen WSON-Gehäuse (1 mm Höhe) ausgeführt. Über die ST-Statusleitung (Pin 9) informiert er den ESP32-S3 über den aktiven Versorgungspfad.

## 2.7 STUSB4500QTR – Autonomer USB-PD-Sink-Controller (IC6)

Der STUSB4500QTR von STMicroelectronics (IC6) ist ein autonomer USB-Power-Delivery-Sink-Controller, der ohne Mikrocontroller-Eingriff selbstständig Spannungsprofile mit dem USB-Ladegerät aushandelt (bis 20 V / 5 A = 100 W). Er kommuniziert über CC1/CC2-Leitungen mit dem Host und meldet den ausgehandelten Status über ALERT (aktiv-LOW an GPIO8 des ESP32-S3) sowie RESET. Konfiguration und Statusabfrage erfolgen über I²C (SDA/SCL, GPIO9/GPIO10). Intern speichert der IC das gewünschte Spannungsprofil (12 V wurde im Projekt eingestellt) in einem nichtflüchtigen NVM-Speicher.

## 2.8 BQ29200DRBT – Sekundärer 2S-Zellschutz und Balancer (IC7)

Der BQ29200DRBT von Texas Instruments (IC7) übernimmt das passive Zellen-Balancing des 2S-LiPo-Akkus. Er gleicht Ladungsunterschiede zwischen den beiden Zellen über Shunt-Widerstände aus und sorgt so für eine gleichmäßige Zellspannung im Ladebetrieb. Der Kurzschluss- und Überstromschutz wird vom primären Schutz-IC S-82B2 (IC3) übernommen. Die Pins NetIC7_3 und NetC37_1/NetC37_2 verbinden ihn mit den Filterschaltkreisen und dem Akku.

## 2.9 LMR51430XDDCR – 3,3-V-Buck-Konverter (PS1)

Der LMR51430XDDCR von Texas Instruments (PS1) ist ein synchroner Step-Down-Regler (Buck-Konverter), der die Akkuspannung (VSYS, bis 8,4 V bei vollem 2S-Akku) auf 3,3 V (3V3) für alle digitalen ICs – ESP32-S3, STUSB4500, BQ29200 und weitere – herabsetzt. Er ist im kleinen WSON-Gehäuse (1,1 mm Höhe) ausgeführt und erreicht Wirkungsgrade von typisch 95 %. Die Taktfrequenz beträgt 3 MHz, was kleine externe Bauelemente (Induktivität L1 = ASPI-4030S-5R6M-T, 5,6 µH) erlaubt. Der EN-Pin (Enable) ist mit GPIO3 des ESP32-S3 verbunden, sodass die 3,3-V-Schiene bei Bedarf per Software abgeschaltet werden kann.

# 3 Projektdurchführung

## 3.1 Planung und Materialauswahl

In der Planungsphase (September 2025) wurden Anforderungen, Kommunikationsprotokoll und Bauteilauswahl festgelegt. Als Mikrocontroller wurde der ESP32-S3 gewählt, da er WLAN, Bluetooth und ausreichend GPIOs für SPI, I²C und PWM auf einer kompakten Modulfläche vereint. Für die Motoransteuerung fiel die Entscheidung auf einen bürstenlosen Motor mit DRV8323S-Gate-Treiber, um höhere Effizienz und Drehzahl gegenüber bürstenbehäfteten DC-Motoren zu erreichen. Als Steuerungsschnittstelle wurde eine Flutter-Smartphone-App mit WebSocket-Kommunikation konzipiert, um plattformübergreifend (Android und iOS) eine intuitive Joystick-Oberfläche bereitzustellen.

## 3.2 Hardwareaufbau

Der Hardware-Aufbau basiert auf einer selbst entwickelten Platine (PCB), die in Altium Designer entworfen wurde. Das ESP32-S3-WROOM-1-N8-Modul ist als zentrales Element platziert und kommuniziert über den SPI-Bus (GPIO5–GPIO8, GPIO16, GPIO39) mit dem DRV8323S-Gate-Treiber. Die sechs PWM-Signale für die 3-Phasen-Vollbrücke (INH_A/B/C: GPIO18, GPIO3, GPIO10; INL_A/B/C: GPIO8, GPIO9, GPIO11) werden direkt vom ESP32-S3 generiert. Der I²C-Bus (SDA: GPIO21, SCL: GPIO47) verbindet den USB-PD-Controller STUSB4500 und den Zell-Balancer BQ29200 mit dem Mikrocontroller. Ein 2S-LiPo-Akku wird über einen 3-poligen Stecker (J1) angeschlossen; der integrierte Ladecontroller MP2615 lädt den Akku aus dem USB-PD-geregelten VBUS-Pfad. Ein LMR51430-Buck-Konverter wandelt die Akkuspannung auf 3,3 V für alle digitalen ICs. Das Fahrgestell basiert auf dem Referenzprojekt und wurde bis auf das Chassis vollständig übernommen; das Chassis selbst wurde an die eigene Platine angepasst und in mehreren Iterationen (V2 bis V18) 3D-gedruckt, bis eine stabile und passgenaue Basis für PCB, Motor und Akku erreicht wurde.

## 3.3 Softwareentwicklung

Die Firmware wurde mit PlatformIO (ESP-IDF-Framework) entwickelt. Die Firmware gliedert sich in mehrere Module: main.cpp für den Einstiegspunkt und WiFi-Setup, batterie.cpp für die ADC-basierte Spannungsmessung des 2S-LiPo-Akkus über Spannungsteiler (GPIO13/GPIO14) sowie Übertragung an die App, usbpd.cpp für die I²C-Kommunikation mit dem STUSB4500-USB-PD-Controller sowie die BLDC-Motoransteuerung über den DRV8323S via SPI und sechs LEDC-PWM-Kanäle. Die Flutter-Smartphone-App wurde parallel dazu entwickelt und bietet einen virtuellen Joystick mit konfigurierbarer Empfindlichkeit, Gamepad-Controller-Unterstützung, UDP-Discovery zur automatischen Server-Suche im Netzwerk (TCP als Fallback) sowie ein Entwickler-Panel (DevPanel) zur Diagnose. App-Builds wurden für Android und iOS bereitgestellt (CocoaPods-Integration).

## 3.4 Inbetriebnahme und Test

Nach der ersten Bestückung und dem Flashen der Firmware wurden beim PCB-Test (Dezember 2025) mehrere Fehler identifiziert, die dokumentiert und in einer zweiten PCB-Version (ab März 2026) behoben wurden. Im weiteren Verlauf wurden Batterie-Lade- und Schutzschaltung getestet, die WebSocket-Verbindung zwischen App und Fahrzeug verifiziert sowie die Servo-Lenkung in Betrieb genommen. Die Joystick-Empfindlichkeit der App wurde iterativ optimiert. OTA-Firmware-Updates wurden als Erweiterung implementiert, um zukünftige Firmware-Aktualisierungen ohne USB-Kabel zu ermöglichen.

## 3.5 PCB- und Schaltplan-Übersicht

Die folgenden Abbildungen zeigen das PCB-Layout sowie den Schaltplan in beiden Versionen: die erste Version (bestellt und getestet, Dezember 2025) sowie die zweite, überarbeitete Version (ab März 2026). Beim Test der ersten Version wurden mehrere Fehler identifiziert, die in der zweiten Version behoben wurden: Die Pull-Beschaltung der Einganspins des TPS2121-Power-Mux (IC4) war falsch dimensioniert und führte zu undefiniertem Umschaltverhalten. Die CC-Leitungen des STUSB4500 (IC6) waren falsch terminiert, weshalb die USB-PD-Aushandlung nicht funktionierte – in der zweiten Version wurden die CC-Pull-Down-Widerstände korrekt dimensioniert und ein dediziertes Entkopplungsnetzwerk ergänzt. Der BQ29200-Zellschutz (IC7) war aufgrund eines falschen Footprints nicht lötbar und wurde korrigiert. Beim MP2615-Ladecontroller (IC2) wurden Bestückungsfehler behoben, die zu instabilem Ladeverhalten geführt hatten. Zusätzlich wurden im Schaltplan Entkopplungskondensatoren, Jumper-Optionen für einfachere Inbetriebnahme sowie das thermische Layout des LMR51430-Buck-Konverters (PS1) verbessert.

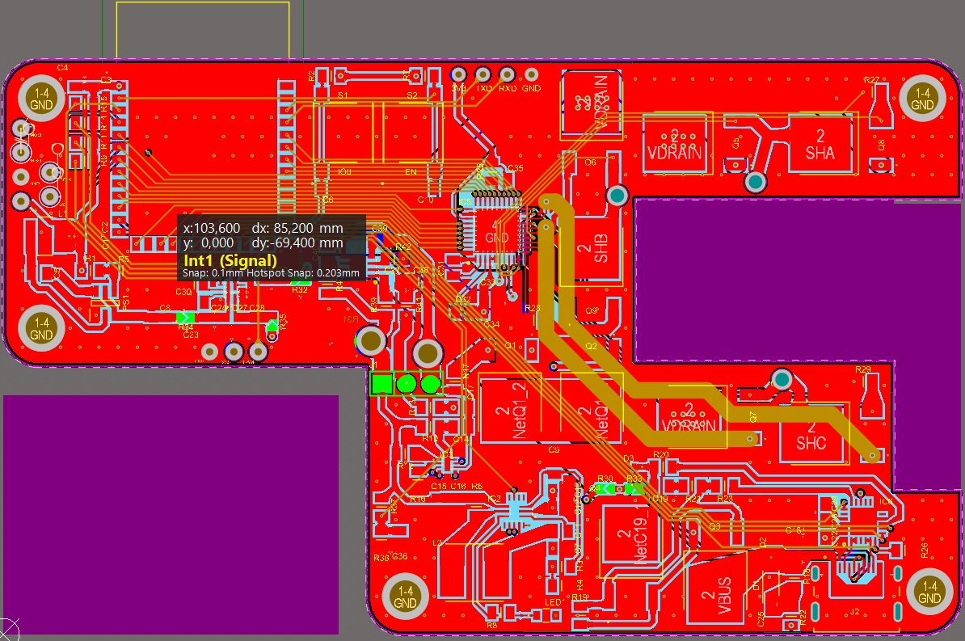
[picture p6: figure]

Abbildung 1: PCB-Layout erste Version (bestellt Dezember 2025, Altium Designer)

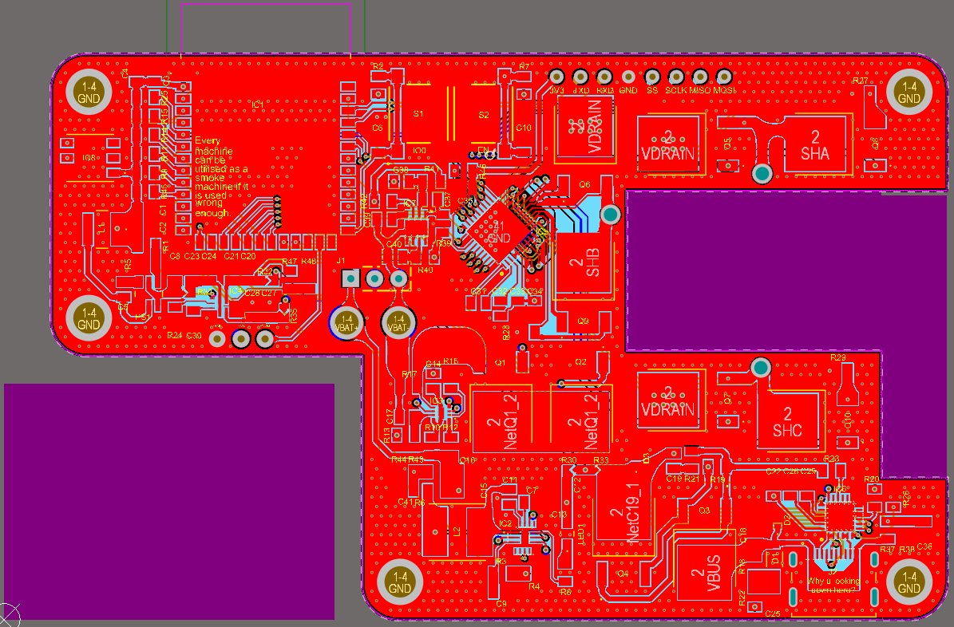
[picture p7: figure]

Abbildung 2: PCB-Layout zweite Version (überarbeitet ab März 2026, Altium Designer)

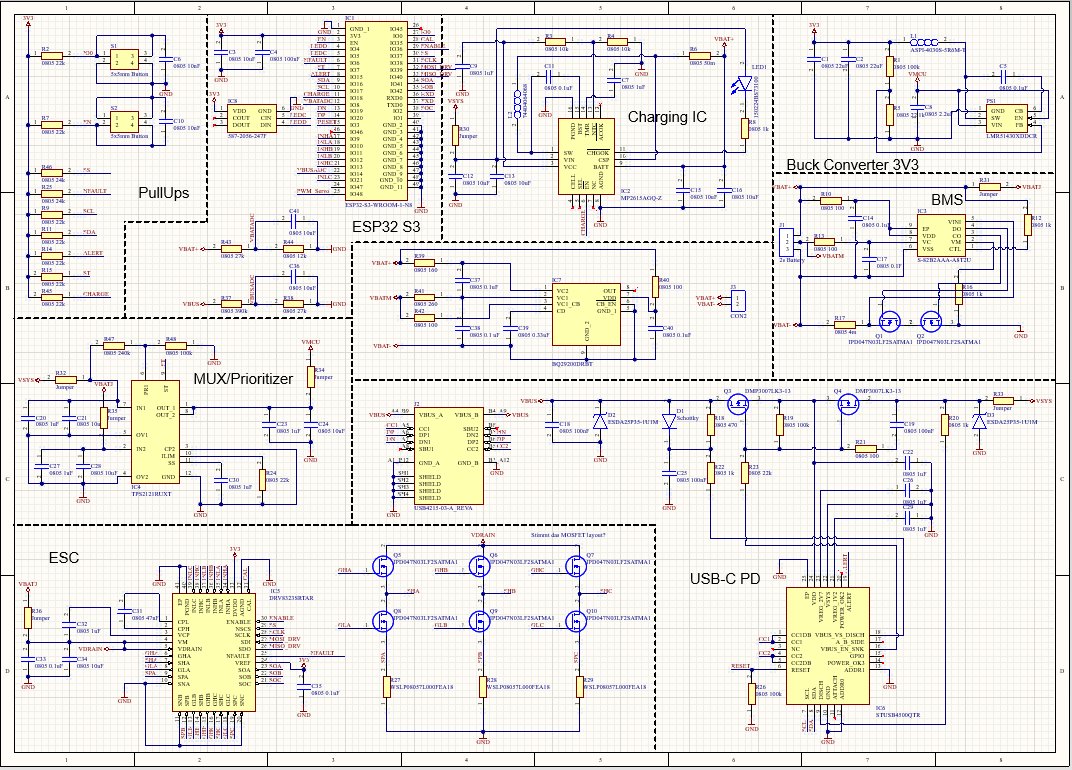
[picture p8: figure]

Abbildung 3: Schaltplan erste Version (ESP32-S3-WROOM-1-N8, DRV8323SRTAR, MP2615AGQ-Z, STUSB4500QTR, TPS2121RUXT, S-82B2AAA-A8T2U, BQ29200DRBT)

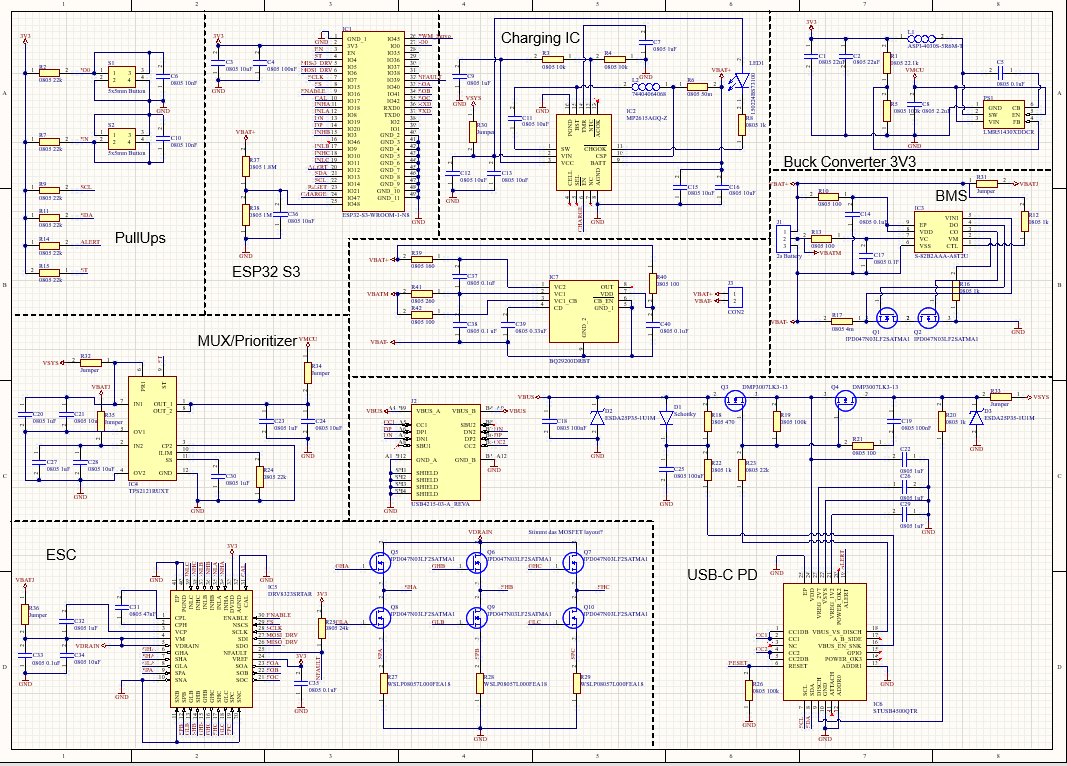
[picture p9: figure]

Abbildung 4: Schaltplan zweite Version (korrigierte Beschaltung IC4, IC6, IC7, PS1; zusätzliche Entkopplungskondensatoren und Jumper)

# 4 Verwendete Hardware

Nachfolgend sind alle im Projekt eingesetzten Bauteile aufgelistet:

Bauteil / Referenz | Bezeichnung / Typ | Stk. | Funktion
IC1 – Mikrocontroller | ESP32-S3-WROOM-1-N8 (8 MB Flash) | 1 | Hauptmikrocontroller: WiFi, BLE, SPI, I²C, PWM
IC2 – Ladecontroller | MP2615AGQ-Z | 1 | Synchroner Buck-Boost-Ladecontroller für 2S-LiPo
IC3 – Batterieschutz | S-82B2AAA-A8T2U | 1 | Überspannungs-/Unterspannungsschutz 2S
IC4 – Power-Mux | TPS2121RUXT | 1 | Auswahl zwischen USB-PD-Pfad und Akku
IC5 – Gate-Treiber | DRV8323SRTAR | 1 | 3-Phasen-BLDC-Gate-Treiber, SPI-konfigurierbar
IC6 – USB-PD | STUSB4500QTR | 1 | USB-C Power Delivery Sink (bis 100 W)
IC7 – Zell-Balancer | BQ29200DRBT | 1 | 2S-LiPo-Zellausgleich
PS1 – Buck-Konverter | LMR51430XDDCR | 1 | 3,3 V-Versorgung für MCU und ICs
Q5–Q10 – MOSFETs | IPD047N03LF2SATMA1 (N-Ch, 30 V) | 6 | 3-Phasen-Vollbrücke für BLDC-Motor
Motor | BLDC Mini1410 2500 kV | 1 | Antriebsmotor des Fahrzeugs
J1 – Akkuanschluss | 3-poliger Stecker (2S) | 1 | 2S-LiPo-Akkuanschluss
J2 – USB-C | USB4215-03-A (24-polig) | 1 | Laden via USB-PD und USB 2.0 Daten
Akku | 2S LiPo (2× 3,7 V) | 1 | Fahrzeugstromversorgung
S1 / S2 – Taster | 5×5 mm Taster | 2 | Boot-Taster (IO0) und Reset-Taster (EN)
Fahrgestell | 3D-gedruckt, PLA, Version 18 | 1 | Mechanische Basis (18 Iterationen)
Steuerung | Smartphone mit Flutter-App | 1 | Joystick-Steuerung via WiFi/WebSocket

# 5 Softwareübersicht

## 5.1 Firmware ESP32-S3 (Fahrzeug)

Die Firmware ist in C++ mit PlatformIO (ESP-IDF-Framework) entwickelt und in Module aufgeteilt. main.cpp initialisiert die WiFi-Verbindung: Beim Start versucht der ESP32-S3 sich mit einem gespeicherten WLAN zu verbinden; findet er keines, öffnet er einen Soft-AP und startet einen Webserver zur WLAN-Konfiguration (SSID/Passwort eintragen). Nach Neustart mit gültigem WLAN betreibt main.cpp den WebSocket-Server und empfängt Steuerbefehle (JSON oder Rohwerte), die an die Motorsteuerungslogik weitergeleitet werden. Die BLDC-Kommutierung erfolgt durch sechs LEDC-PWM-Kanäle (INH_A/B/C, INL_A/B/C) in Kombination mit dem DRV8323S, der per SPI konfiguriert und auf Fehlerzustände (nFAULT) überwacht wird. batterie.cpp liest die Zellspannungen des 2S-LiPo-Akkus über ADC-Spannungsteiler (GPIO13/GPIO14) aus und überträgt den Ladezustand an verbundene App-Clients. usbpd.cpp kommuniziert über I²C mit dem STUSB4500, um das USB-Ladeprofil (Spannung, Stromstärke) zu konfigurieren.

## 5.2 Flutter-Smartphone-App

Die Flutter-App läuft auf Android und iOS und verbindet sich über WiFi per WebSocket mit dem ESP32-S3-Fahrzeug. Ein virtueller Joystick-Widget überträgt X/Y-Ausschläge in Echtzeit; alternativ kann ein physischer Gamepad-Controller verwendet werden. Die App erkennt den Server automatisch über UDP-Discovery-Broadcasts im lokalen Netzwerk; als Fallback ist eine TCP-basierte Discovery implementiert. Die zuletzt verwendete Server-URL wird über SharedPreferences gespeichert. Ein integriertes DevPanel zeigt Verbindungsstatus, Latenz und empfangene Sensordaten (Batteriespannung) an und erleichtert die Fehlersuche während der Entwicklung.

## 5.3 Softwareablauf-Flussdiagramme

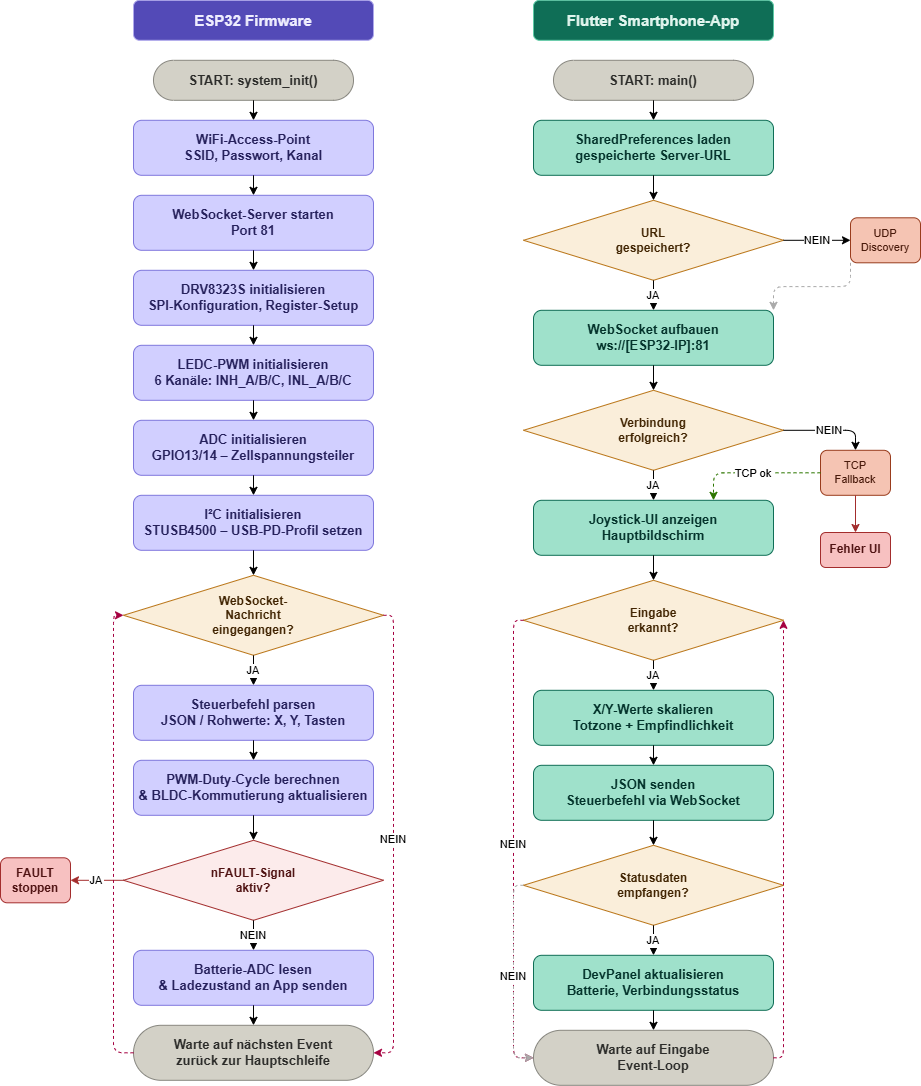
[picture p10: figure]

ESP32-S3 Firmware und Flutter Smartphone App – Ablaufdiagramm

Abbildung 5: Flussdiagramm von Esp32 und Smartphone App

## 5.3 Verwendete Bibliotheken

Bibliothek / Paket | Version | Verwendungszweck
esp_websocket_client | ESP-IDF integriert | WebSocket-Server am ESP32-S3 (Steuerempfang, Status-Push)
esp_wifi | ESP-IDF integriert | WiFi-Access-Point-Konfiguration (Soft-AP)
driver/spi_master | ESP-IDF integriert | SPI-Kommunikation mit DRV8323S-Gate-Treiber
driver/i2c | ESP-IDF integriert | I²C: STUSB4500 (USB-PD) und BQ29200 (Zell-Balancer)
driver/ledc | ESP-IDF integriert | LEDC-PWM: 6 Kanäle für BLDC-Kommutierung (INH/INL)
esp_adc | ESP-IDF integriert | ADC-Spannungsmessung für 2S-LiPo-Zellenüberwachung
web_socket_channel | ^2.4.0 | Flutter: WebSocket-Verbindung zur ESP32-S3-Firmware
flutter_joystick | ^0.1.3 | Flutter: virtueller Joystick-Widget
gamepad | ^3.1.0 | Flutter: physischer Gamepad-Controller-Support
shared_preferences | ^2.2.3 | Flutter: Persistierung der Server-URL
udp_broadcast (eigen) | — | Flutter: UDP-Discovery zur automatischen Server-Erkennung

# 6 Ergebnisse und Auswertung

## 6.1 Messungen

## 6.1.1 USB PD Versorgungsspannung

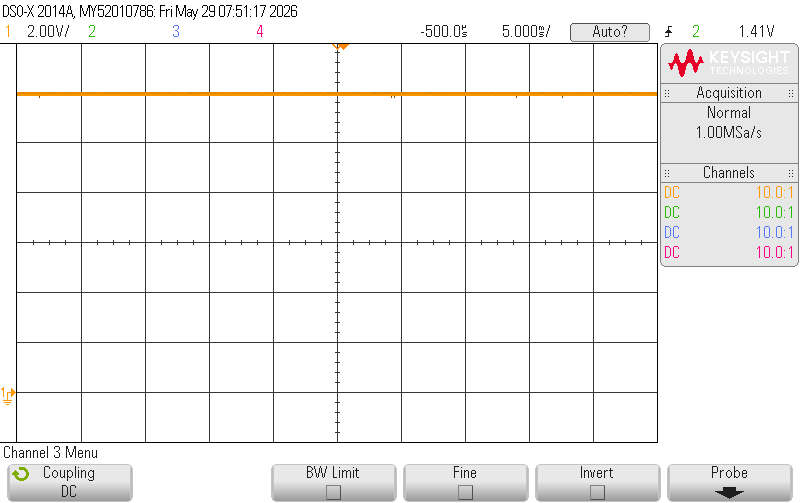
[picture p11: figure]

Wir haben die USB-PD Versorgungsspannung gemessen (siehe Abb. 2). Man kann sehen, dass eine stabile DC-Spannung von 12V anliegt. Die komplett flache Linie zeigt, dass die USB-PD Aushandlung erfolgreich war und die Spannung keinerlei Ripple oder Einbrüche aufweist.

Abbildung 6: USB PD Versorgungsspannung

## 6.1.2 Wireshark Kommunikation

Hier wurde der Netzwerkverkehr des ESP32 mit Wireshark mitgeschnitten. Man kann sehen, dass der ESP32 (MAC: e4:b0:63:91:93:b9, Espressif) einen UDP-Broadcast auf Port 49352 sendet. Im Data-Payload ist der String $..ESP_RC_HERE ws://0.0.0.2e:30a:38 31 2f erkennbar – der ESP32 broadcastet also seinen WebSocket-Endpunkt ins Netzwerk, damit Clients ihn automatisch finden können.

Abbildung 7: Esp32 Beacon

Hier haben wir den Discovery-Mechanismus des RC-Systems mit Wireshark mitgeschnitten. Man kann sehen, dass das Smartphone (MAC: 5a:eb:13:07:13:df) einen UDP-Broadcast an 192.168.4.255 auf Port 49352 sendet. Im Data-Payload ist der String ~ESP_RC_DISCOVER erkennbar – das Smartphone sucht aktiv nach verfügbaren ESP_RC-Controllern im Netzwerk. Zusammen mit dem vorherigen Beacon-Frame ergibt sich damit das vollständige Discovery-Protokoll: Der ESP32 announced sich per UDP-Beacon, das Smartphone sucht aktiv per Broadcast.

Abbildung 8: Client antwort

## 6.1.3 Ladespannung

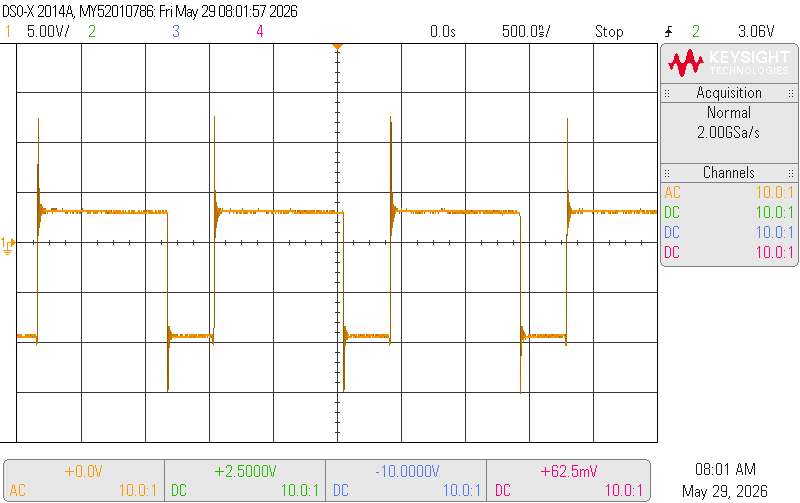
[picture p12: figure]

Hier haben wir die Ladespannung des Akkus gemessen. Man kann sehen, dass die Spannung in regelmäßigen Abständen kurz hochschießt (Spikes bis ~15V) und dann wieder auf den Ruhepegel fällt – typisches Verhalten eines Ladereglers, der in Phasen lädt und dabei die Akkuspannung prüft. Der DC-Mittelwert liegt bei ca. 2.5V.(siehe Abb. 5)

Abbildung 9: Ladespannung für den Lipo Akku (AC-Messung)

## 6.1.4 Motor Phasenmessung

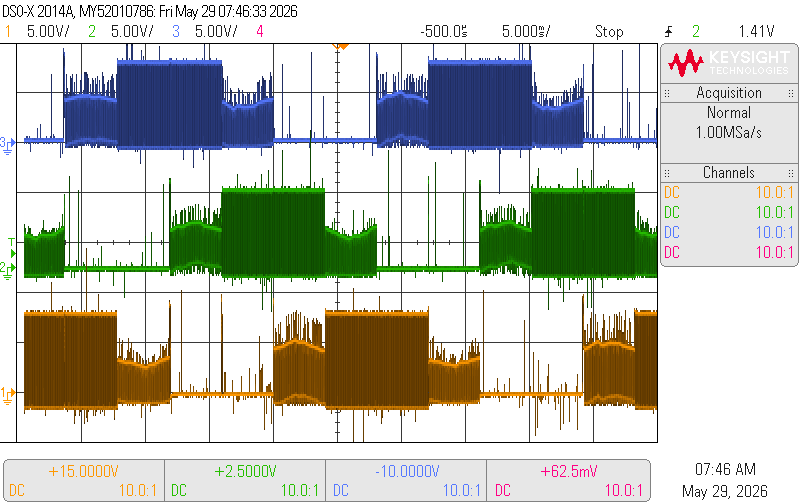
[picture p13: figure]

Hier haben wir die drei Phasen des Brushless-DC-Motors gleichzeitig gemessen (Kanal 1/2/3, je 5V/div). Man kann sehen, dass die drei Phasen (blau, grün, orange)(siehe Abb.6) versetzt zueinander geschaltet werden – klassisches BLDC-Kommutierungsmuster. Die Signale zeigen deutlich die PWM-Ansteuerung des ESC mit den charakteristischen Schaltflanken und dem Übersprechen zwischen den Phasen.

Abbildung 10: Motorphasen Messung

## 6.1.5 Servo Positionsmessung

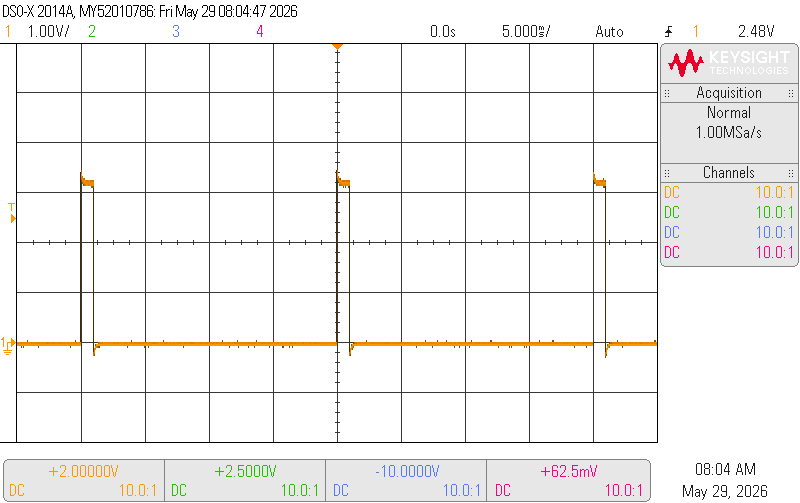
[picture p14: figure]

Hier haben wir das PWM-Signal des Servos bei Vollausschlag nach links gemessen. Man kann sehen, dass der Puls eine Breite von ca. 1ms hat (siehe Abb.7), was dem linken Endanschlag des Servos entspricht. Das Signal wiederholt sich mit der typischen Servo-Frequenz von ~50Hz (Periode ~20ms).

Abbildung 11: Servo links eingeschlagen

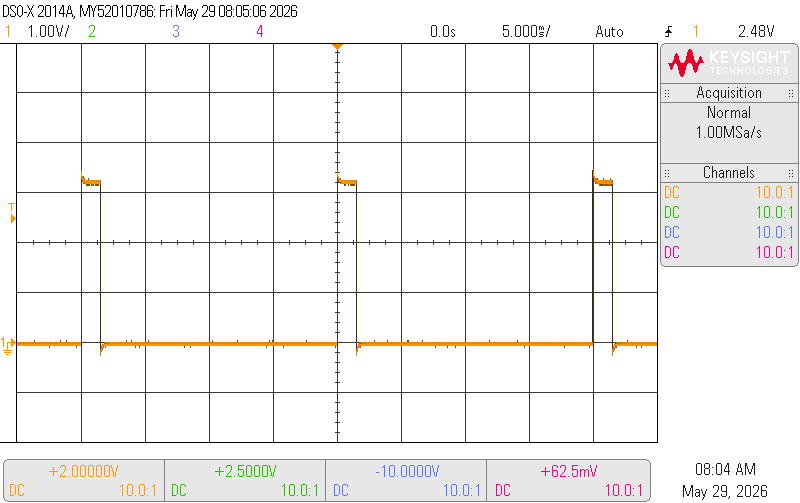
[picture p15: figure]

Hier haben wir das PWM-Signal des Servos in Neutralstellung gemessen. Man kann sehen, dass der Puls auf ca. 1.5ms liegt – genau in der Mitte zwischen den beiden Endanschlägen. Der Servo befindet sich damit in der Geradeausstellung, was der Mittenposition (1500µs) entspricht.

Abbildung 12: Servo neutral

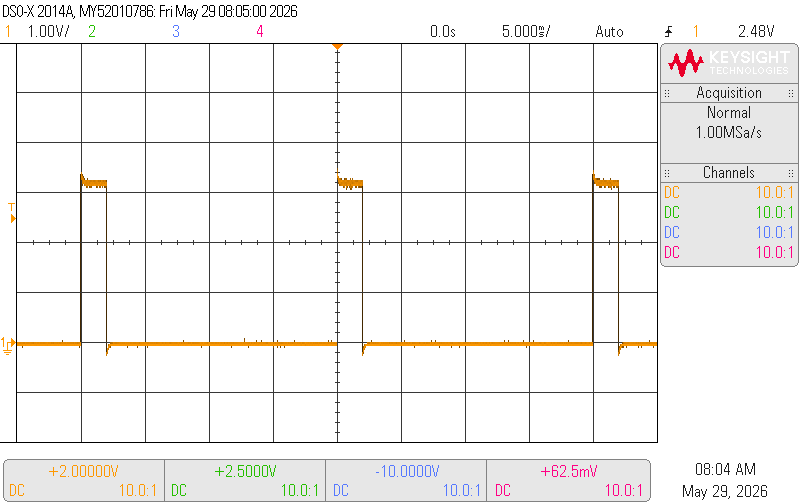
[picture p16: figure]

Hier haben wir das PWM-Signal des Servos bei Vollausschlag nach rechts gemessen. Man kann sehen, dass der Puls mit ca. 2ms am längsten ist, was dem rechten Endanschlag entspricht. Im Vergleich zu links (1ms) und neutral (1.5ms) ist die Pulsbreiten-Abstufung klar erkennbar – die PWM-Steuerung funktioniert korrekt über den vollen Lenkbereich.

Abbildung 13: Servo rechts eingeschlagen

## 6.2 Funktionsergebnis

Das fertiggestellte ESP-RC-Car erfüllt die wesentlichen definierten Anforderungen. Das Fahrzeug lässt sich über die Flutter-App per WiFi-WebSocket-Verbindung in Echtzeit steuern; der virtuelle Joystick sowie ein physischer Gamepad-Controller wurden erfolgreich in Betrieb genommen. Die BLDC-Motoransteuerung via DRV8323S und sechs LEDC-PWM-Kanäle funktioniert stabil, und die Servo-Lenkung reagiert reproduzierbar auf Lenkbefehle der App. Das Energiemanagement-System (USB-PD-Laden, 2S-LiPo-Schutz, Zell-Balancer) arbeitet korrekt; die Batteriespannung wird in Echtzeit in der App angezeigt. Die WebSocket-Verbindung zeigte im Test eine niedrige Latenz und verblieb während der Fahrt stabil im gemeinsamen WLAN-Netzwerk.

## 6.2 Aufgetretene Probleme und Lösungen

PCB-Fehler in Revision 1: Beim ersten PCB-Test (Dezember 2025) wurden mehrere Layout- und Bestückungsfehler identifiziert (fehlerhafte Signalpegel am DRV8323S, falsche Pull-up-/Pull-down-Beschaltung). Gelöst durch eine zweite PCB-Revision (ab März 2026) mit korrigierten Netzlisten in Altium Designer.

Fahrgestell-Passform: Das Chassis des Referenzprojekts passte nicht zur eigenen Platine und musste neu konstruiert werden. über 18 Druckversionen (V2–V18) wurden Passungenauigkeiten bei der Motorhalterung und dem PCB-Einschub iterativ behoben, bis eine stabile Endversion erreicht wurde.

Joystick-Empfindlichkeit: Der virtuelle Joystick übertrug anfangs zu feinfühlige Werte, was zu zittrigen Fahrbewegungen führte. Gelöst durch Einführung einer konfigurierbaren Totzone sowie einer Skalierungsfunktion im App-Code.

WebSocket-Verbindungsabbrüche: Bei schlechtem WLAN-Signal riss die WebSocket-Verbindung gelegentlich ab. Behoben durch automatische Reconnect-Logik in der Flutter-App und Erhöhung des Keepalive-Intervalls auf der ESP32-S3-Seite.

# 7 Schlussfolgerung

Das Projekt ESP-RC-Car wurde erfolgreich durchgeführt. Die gesetzten Ziele – Entwicklung einer eigenen Platine, BLDC-Motoransteuerung über den DRV8323S, WiFi-WebSocket-Kommunikation mit einer Flutter-Smartphone-App sowie ein vollständiges Energiemanagement mit USB-Power-Delivery – wurden weitgehend erreicht. Das Projekt vermittelte tiefgehende praktische Erfahrungen in den Bereichen PCB-Design (Altium Designer), Embedded-Software-Entwicklung (PlatformIO/ESP-IDF, C++), plattformübergreifende App-Entwicklung (Flutter/Dart) sowie Leistungselektronik (BLDC-Kommutierung, 3-Phasen-Vollbrücke, Batteriemanagement). Als mögliche Erweiterungen wären eine vollständige Feldorientierte Regelung (FOC) des BLDC-Motors, ein OTA-Firmware-Update-System (bereits prototypisch implementiert) oder eine FPV-Kamera mit Live-Stream in der App denkbar.

# 8 Quellenverzeichnis

[1] Espressif Systems: ESP32-S3 Technical Reference Manual, Version 1.4, 2024. Online: https://www.espressif.com/en/support/documents/technical-documents

[2] Texas Instruments: DRV8323S Three-Phase Smart Gate Driver, Datasheet SLVSEI4, 2023. Online: https://www.ti.com/product/DRV8323S

[3] STMicroelectronics: STUSB4500 Autonomous USB PD Controller, Datasheet, 2022. Online: https://www.st.com/en/interfaces-and-transceivers/stusb4500.html

[4] Monolithic Power Systems: MP2615A Datasheet, 2022. Online: https://www.monolithicpower.com/en/mp2615a.html

[5] Texas Instruments: BQ29200 2-Series Cell Protector, Datasheet SLUSAZ4, 2019. Online: https://www.ti.com/product/BQ29200

[6] Infineon Technologies: IPD047N03LF2 Power MOSFET, Datasheet, 2021. Online: https://www.infineon.com

[7] Espressif Systems: ESP-IDF Programming Guide, v5.x, 2024. Online: https://docs.espressif.com/projects/esp-idf/en/latest/

[8] PlatformIO: PlatformIO IDE & Build System Documentation, 2024. Online: https://docs.platformio.org

[9] Flutter Dev Team: Flutter Documentation, flutter.dev, abgerufen 27.05.2026. Online: https://docs.flutter.dev

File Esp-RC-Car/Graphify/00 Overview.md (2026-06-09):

---
source_file: "Esp-RC-Car/Graphify/00 Overview.md"
type: "document"
community: "Firmware Tasks & Modules"
tags:
  - graphify/document
  - graphify/EXTRACTED
  - community/Firmware_Tasks__Modules
---

# 00 Overview

## Connections
- [[App Overview]] - `references` [EXTRACTED]
- [[Firmware Overview]] - `references` [EXTRACTED]
- [[Motor & Treiber]] - `references` [EXTRACTED]
- [[PCB]] - `references` [EXTRACTED]
- [[drv8323 (doc)]] - `references` [EXTRACTED]
- [[rc_battery (doc)]] - `references` [EXTRACTED]
- [[rc_motor (doc)]] - `references` [EXTRACTED]
- [[rc_network (doc)]] - `references` [EXTRACTED]
- [[rc_ota (doc)]] - `references` [EXTRACTED]
- [[rc_pins (doc)]] - `references` [EXTRACTED]
- [[rc_recovery (doc)]] - `references` [EXTRACTED]
- [[rc_settings (doc)]] - `references` [EXTRACTED]
- [[rc_steering (doc)]] - `references` [EXTRACTED]
- [[rc_websocket (doc)]] - `references` [EXTRACTED]

#graphify/document #graphify/EXTRACTED #community/Firmware_Tasks__Modules

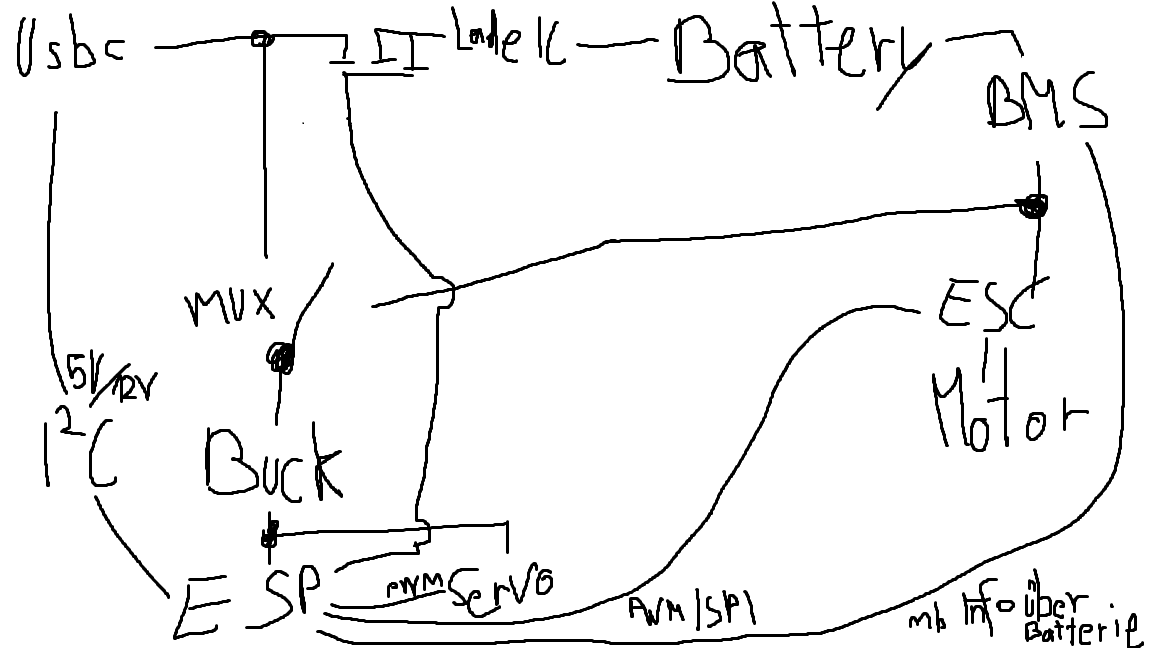
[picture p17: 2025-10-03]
SchaltungSkizze.png

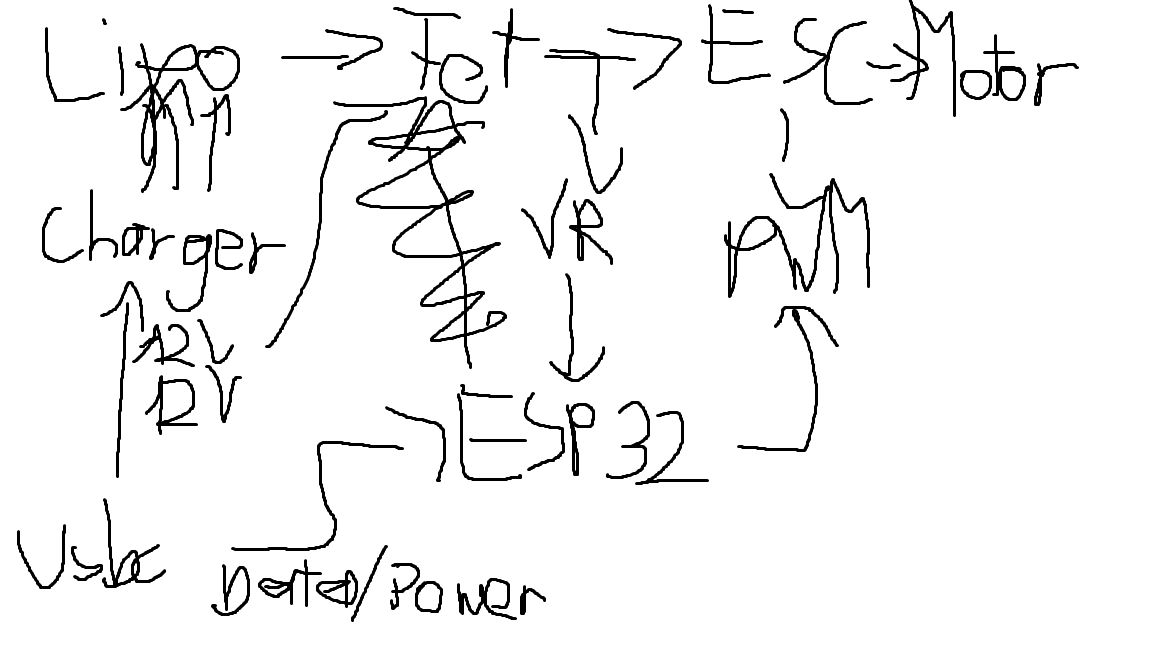
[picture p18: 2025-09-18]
Powersystem.png

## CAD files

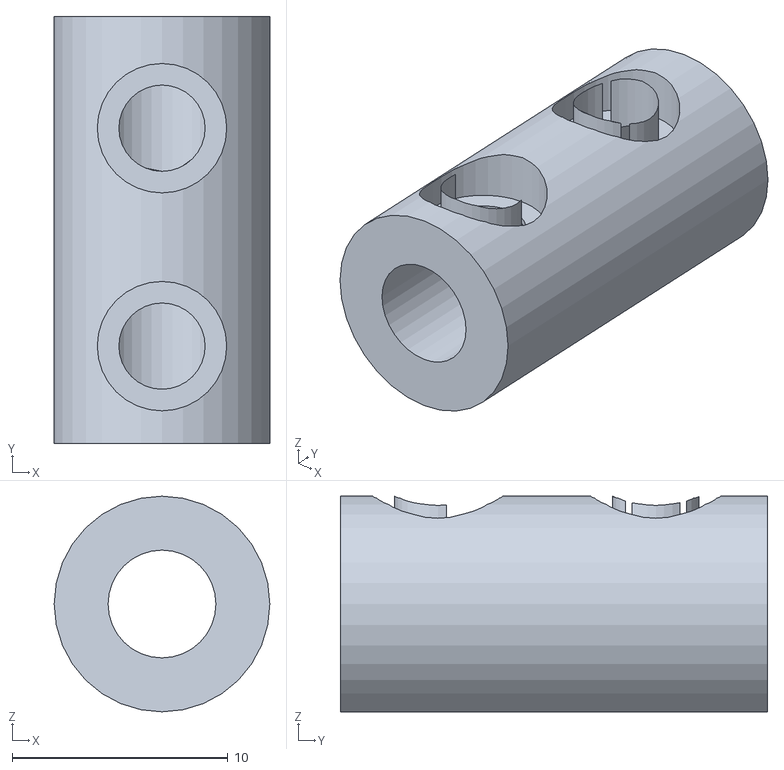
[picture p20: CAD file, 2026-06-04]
STL/verbindung v1.stl
10.0 x 19.8 x 10.0

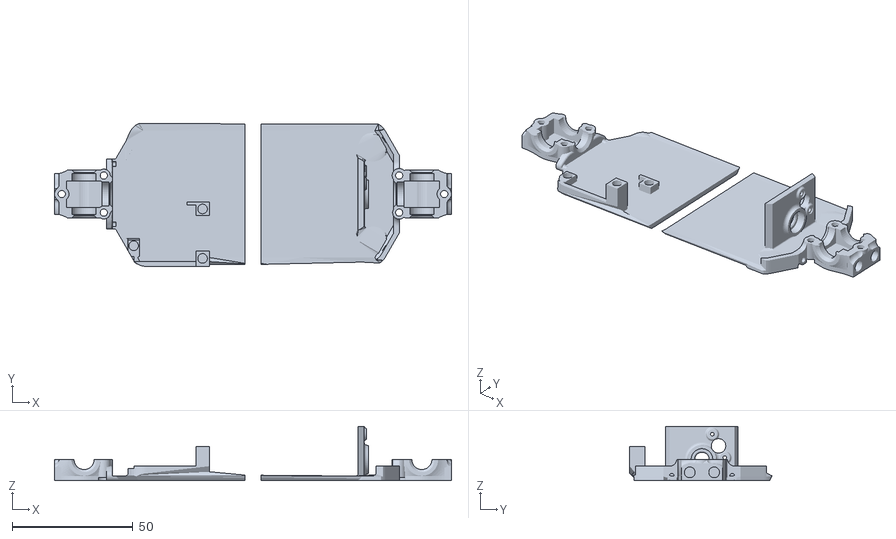
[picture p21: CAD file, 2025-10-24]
STL/Chassi V8.stl
164.5 x 59.2 x 22.5

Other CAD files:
STL/Chassi V8.obj
STL/verbindung v1.blend

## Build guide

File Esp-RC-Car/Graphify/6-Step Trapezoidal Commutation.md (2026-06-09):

---
source_file: "Esp-RC-Car/Graphify/6-Step Trapezoidal Commutation.md"
type: "concept"
community: "BLDC Commutation Design"
tags:
  - graphify/concept
  - graphify/EXTRACTED
  - community/BLDC_Commutation_Design
---

# 6-Step Trapezoidal Commutation

## Connections
- [[BLDC Motor Test Spin Design]] - `references` [EXTRACTED]
- [[Motor Driver Rewrite Design Spec]] - `references` [EXTRACTED]
- [[rc_motor_apply_phase]] - `implements` [EXTRACTED]

#graphify/concept #graphify/EXTRACTED #community/BLDC_Commutation_Design

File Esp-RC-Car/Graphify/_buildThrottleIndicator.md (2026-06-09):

---
source_file: "Esp-RC-Car/Graphify/_buildThrottleIndicator.md"
type: "code"
community: "App Telemetry Widgets"
tags:
  - graphify/code
  - graphify/EXTRACTED
  - community/App_Telemetry_Widgets
---

# _buildThrottleIndicator

## Connections
- [[gamepad_status.dart]] - `references` [EXTRACTED]

#graphify/code #graphify/EXTRACTED #community/App_Telemetry_Widgets

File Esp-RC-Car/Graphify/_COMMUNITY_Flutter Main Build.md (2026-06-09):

---
type: community
cohesion: 0.40
members: 5
---

# Flutter Main Build

**Cohesion:** 0.40 - moderately connected
**Members:** 5 nodes

## Members
- [[Padding (1)]] - code - Esp-RC-Car/Graphify/Padding_1.md
- [[build]] - code - Esp-RC-Car/Graphify/build.md
- [[dev_panel.dart]] - code - Esp-RC-Car/Graphify/Padding_1.md
- [[main.dart]] - code - Esp-RC-Car/Graphify/packageproviderprovider.dart.md
- [[packageproviderprovider.dart]] - code - Esp-RC-Car/Graphify/packageproviderprovider.dart.md

## Live Query (requires Dataview plugin)

```dataview
TABLE source_file, type FROM #community/Flutter_Main_Build
SORT file.name ASC
```

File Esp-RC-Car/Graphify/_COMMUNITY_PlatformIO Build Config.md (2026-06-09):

---
type: community
cohesion: 0.50
members: 4
---

# PlatformIO Build Config

**Cohesion:** 0.50 - moderately connected
**Members:** 4 nodes

## Members
- [[build (library.json)]] - code - Esp-RC-Car/Graphify/build_4.md
- [[flags]] - code - Esp-RC-Car/Graphify/build_4.md
- [[library.json]] - code - Esp-RC-Car/Graphify/build_4.md
- [[srcFilter]] - code - Esp-RC-Car/Graphify/build_4.md

## Live Query (requires Dataview plugin)

```dataview
TABLE source_file, type FROM #community/PlatformIO_Build_Config
SORT file.name ASC
```

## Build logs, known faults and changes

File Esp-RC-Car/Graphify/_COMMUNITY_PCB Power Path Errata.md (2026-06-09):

---
type: community
cohesion: 0.67
members: 3
---

# PCB Power Path Errata

**Cohesion:** 0.67 - moderately connected
**Members:** 3 nodes

## Members
- [[PCB Errata  Known Issues]] - document - Esp-RC-Car/Graphify/USB PD IC MOSFET Gate Wired to Wrong Pin.md
- [[USB PD IC MOSFET Gate Wired to Wrong Pin]] - rationale - Esp-RC-Car/Graphify/USB PD IC MOSFET Gate Wired to Wrong Pin.md
- [[USB-C PD 12V Power Input]] - concept - Esp-RC-Car/Graphify/USB PD IC MOSFET Gate Wired to Wrong Pin.md

## Live Query (requires Dataview plugin)

```dataview
TABLE source_file, type FROM #community/PCB_Power_Path_Errata
SORT file.name ASC
```

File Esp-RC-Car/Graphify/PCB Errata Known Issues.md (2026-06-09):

---
source_file: "Esp-RC-Car/Graphify/USB PD IC MOSFET Gate Wired to Wrong Pin.md"
type: "document"
community: "PCB Power Path Errata"
tags:
  - graphify/document
  - graphify/EXTRACTED
  - community/PCB_Power_Path_Errata
---

# PCB Errata / Known Issues

## Connections
- [[USB PD IC MOSFET Gate Wired to Wrong Pin]] - `references` [EXTRACTED]

#graphify/document #graphify/EXTRACTED #community/PCB_Power_Path_Errata

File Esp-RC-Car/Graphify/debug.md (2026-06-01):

---
source_file: "Code/boards/esp32s3wroom2.json"
type: "code"
community: "Community None"
location: "L31"
tags:
  - graphify/code
  - graphify/EXTRACTED
  - community/Community_None
---

# debug

## Connections
- [[default_tool]] - `contains` [EXTRACTED]
- [[esp32s3wroom2.json]] - `contains` [EXTRACTED]
- [[onboard_tools]] - `contains` [EXTRACTED]
- [[openocd_target]] - `contains` [EXTRACTED]

#graphify/code #graphify/EXTRACTED #community/Community_None

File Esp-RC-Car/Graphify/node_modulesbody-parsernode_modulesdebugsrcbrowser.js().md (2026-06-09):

---
source_file: ".obsidian/plugins/obsidian-local-rest-api/main.js"
type: "code"
community: "Obsidian REST API Routes"
location: "L23954"
tags:
  - graphify/code
  - graphify/EXTRACTED
  - community/Obsidian_REST_API_Routes
---

# "node_modules/body-parser/node_modules/debug/src/browser.js"()

## Connections
- [[main.js]] - `contains` [EXTRACTED]

#graphify/code #graphify/EXTRACTED #community/Obsidian_REST_API_Routes

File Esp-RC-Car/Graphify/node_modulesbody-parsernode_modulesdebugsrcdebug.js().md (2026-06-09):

---
source_file: ".obsidian/plugins/obsidian-local-rest-api/main.js"
type: "code"
community: "Obsidian REST API Routes"
location: "L23845"
tags:
  - graphify/code
  - graphify/EXTRACTED
  - community/Obsidian_REST_API_Routes
---

# "node_modules/body-parser/node_modules/debug/src/debug.js"()

## Connections
- [[main.js]] - `contains` [EXTRACTED]

#graphify/code #graphify/EXTRACTED #community/Obsidian_REST_API_Routes

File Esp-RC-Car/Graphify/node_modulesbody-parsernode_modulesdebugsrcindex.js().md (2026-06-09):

---
source_file: ".obsidian/plugins/obsidian-local-rest-api/main.js"
type: "code"
community: "Obsidian REST API Routes"
location: "L24162"
tags:
  - graphify/code
  - graphify/EXTRACTED
  - community/Obsidian_REST_API_Routes
---

# "node_modules/body-parser/node_modules/debug/src/index.js"()

## Connections
- [[main.js]] - `contains` [EXTRACTED]

#graphify/code #graphify/EXTRACTED #community/Obsidian_REST_API_Routes

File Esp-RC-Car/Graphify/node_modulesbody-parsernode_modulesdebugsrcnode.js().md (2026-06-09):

---
source_file: ".obsidian/plugins/obsidian-local-rest-api/main.js"
type: "code"
community: "Obsidian REST API Routes"
location: "L24038"
tags:
  - graphify/code
  - graphify/EXTRACTED
  - community/Obsidian_REST_API_Routes
---

# "node_modules/body-parser/node_modules/debug/src/node.js"()

## Connections
- [[main.js]] - `contains` [EXTRACTED]

#graphify/code #graphify/EXTRACTED #community/Obsidian_REST_API_Routes

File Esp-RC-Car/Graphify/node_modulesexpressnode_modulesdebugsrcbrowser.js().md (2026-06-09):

---
source_file: ".obsidian/plugins/obsidian-local-rest-api/main.js"
type: "code"
community: "Obsidian REST API Routes"
location: "L40770"
tags:
  - graphify/code
  - graphify/EXTRACTED
  - community/Obsidian_REST_API_Routes
---

# "node_modules/express/node_modules/debug/src/browser.js"()

## Connections
- [[main.js]] - `contains` [EXTRACTED]

#graphify/code #graphify/EXTRACTED #community/Obsidian_REST_API_Routes

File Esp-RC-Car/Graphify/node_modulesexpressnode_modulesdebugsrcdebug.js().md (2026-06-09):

---
source_file: ".obsidian/plugins/obsidian-local-rest-api/main.js"
type: "code"
community: "Obsidian REST API Routes"
location: "L40661"
tags:
  - graphify/code
  - graphify/EXTRACTED
  - community/Obsidian_REST_API_Routes
---

# "node_modules/express/node_modules/debug/src/debug.js"()

## Connections
- [[main.js]] - `contains` [EXTRACTED]

#graphify/code #graphify/EXTRACTED #community/Obsidian_REST_API_Routes

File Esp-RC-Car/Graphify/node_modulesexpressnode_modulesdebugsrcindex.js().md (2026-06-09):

---
source_file: ".obsidian/plugins/obsidian-local-rest-api/main.js"
type: "code"
community: "Obsidian REST API Routes"
location: "L40978"
tags:
  - graphify/code
  - graphify/EXTRACTED
  - community/Obsidian_REST_API_Routes
---

# "node_modules/express/node_modules/debug/src/index.js"()

## Connections
- [[main.js]] - `contains` [EXTRACTED]

#graphify/code #graphify/EXTRACTED #community/Obsidian_REST_API_Routes

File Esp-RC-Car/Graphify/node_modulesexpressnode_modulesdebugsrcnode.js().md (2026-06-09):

---
source_file: ".obsidian/plugins/obsidian-local-rest-api/main.js"
type: "code"
community: "Obsidian REST API Routes"
location: "L40854"
tags:
  - graphify/code
  - graphify/EXTRACTED
  - community/Obsidian_REST_API_Routes
---

# "node_modules/express/node_modules/debug/src/node.js"()

## Connections
- [[main.js]] - `contains` [EXTRACTED]

#graphify/code #graphify/EXTRACTED #community/Obsidian_REST_API_Routes

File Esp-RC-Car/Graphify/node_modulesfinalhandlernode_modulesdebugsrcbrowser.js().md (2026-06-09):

---
source_file: ".obsidian/plugins/obsidian-local-rest-api/main.js"
type: "code"
community: "Obsidian REST API Routes"
location: "L40055"
tags:
  - graphify/code
  - graphify/EXTRACTED
  - community/Obsidian_REST_API_Routes
---

# "node_modules/finalhandler/node_modules/debug/src/browser.js"()

## Connections
- [[main.js]] - `contains` [EXTRACTED]

#graphify/code #graphify/EXTRACTED #community/Obsidian_REST_API_Routes

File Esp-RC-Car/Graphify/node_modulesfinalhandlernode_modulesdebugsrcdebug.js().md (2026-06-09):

---
source_file: ".obsidian/plugins/obsidian-local-rest-api/main.js"
type: "code"
community: "Obsidian REST API Routes"
location: "L39946"
tags:
  - graphify/code
  - graphify/EXTRACTED
  - community/Obsidian_REST_API_Routes
---

# "node_modules/finalhandler/node_modules/debug/src/debug.js"()

## Connections
- [[main.js]] - `contains` [EXTRACTED]

#graphify/code #graphify/EXTRACTED #community/Obsidian_REST_API_Routes

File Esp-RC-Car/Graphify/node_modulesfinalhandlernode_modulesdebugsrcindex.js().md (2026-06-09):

---
source_file: ".obsidian/plugins/obsidian-local-rest-api/main.js"
type: "code"
community: "Obsidian REST API Routes"
location: "L40263"
tags:
  - graphify/code
  - graphify/EXTRACTED
  - community/Obsidian_REST_API_Routes
---

# "node_modules/finalhandler/node_modules/debug/src/index.js"()

## Connections
- [[main.js]] - `contains` [EXTRACTED]

#graphify/code #graphify/EXTRACTED #community/Obsidian_REST_API_Routes

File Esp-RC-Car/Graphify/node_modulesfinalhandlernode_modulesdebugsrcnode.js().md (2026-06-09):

---
source_file: ".obsidian/plugins/obsidian-local-rest-api/main.js"
type: "code"
community: "Obsidian REST API Routes"
location: "L40139"
tags:
  - graphify/code
  - graphify/EXTRACTED
  - community/Obsidian_REST_API_Routes
---

# "node_modules/finalhandler/node_modules/debug/src/node.js"()

## Connections
- [[main.js]] - `contains` [EXTRACTED]

#graphify/code #graphify/EXTRACTED #community/Obsidian_REST_API_Routes

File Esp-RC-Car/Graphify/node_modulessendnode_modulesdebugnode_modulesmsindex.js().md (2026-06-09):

---
source_file: ".obsidian/plugins/obsidian-local-rest-api/main.js"
type: "code"
community: "Obsidian REST API Routes"
location: "L42131"
tags:
  - graphify/code
  - graphify/EXTRACTED
  - community/Obsidian_REST_API_Routes
---

# "node_modules/send/node_modules/debug/node_modules/ms/index.js"()

## Connections
- [[main.js]] - `contains` [EXTRACTED]

#graphify/code #graphify/EXTRACTED #community/Obsidian_REST_API_Routes

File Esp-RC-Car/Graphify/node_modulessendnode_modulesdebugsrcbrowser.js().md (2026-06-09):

---
source_file: ".obsidian/plugins/obsidian-local-rest-api/main.js"
type: "code"
community: "Obsidian REST API Routes"
location: "L42338"
tags:
  - graphify/code
  - graphify/EXTRACTED
  - community/Obsidian_REST_API_Routes
---

# "node_modules/send/node_modules/debug/src/browser.js"()

## Connections
- [[main.js]] - `contains` [EXTRACTED]

#graphify/code #graphify/EXTRACTED #community/Obsidian_REST_API_Routes

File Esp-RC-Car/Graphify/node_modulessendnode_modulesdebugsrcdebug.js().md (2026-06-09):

---
source_file: ".obsidian/plugins/obsidian-local-rest-api/main.js"
type: "code"
community: "Obsidian REST API Routes"
location: "L42229"
tags:
  - graphify/code
  - graphify/EXTRACTED
  - community/Obsidian_REST_API_Routes
---

# "node_modules/send/node_modules/debug/src/debug.js"()

## Connections
- [[main.js]] - `contains` [EXTRACTED]

#graphify/code #graphify/EXTRACTED #community/Obsidian_REST_API_Routes

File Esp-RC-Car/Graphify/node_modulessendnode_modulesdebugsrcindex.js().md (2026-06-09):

---
source_file: ".obsidian/plugins/obsidian-local-rest-api/main.js"
type: "code"
community: "Obsidian REST API Routes"
location: "L42546"
tags:
  - graphify/code
  - graphify/EXTRACTED
  - community/Obsidian_REST_API_Routes
---

# "node_modules/send/node_modules/debug/src/index.js"()

## Connections
- [[main.js]] - `contains` [EXTRACTED]

#graphify/code #graphify/EXTRACTED #community/Obsidian_REST_API_Routes

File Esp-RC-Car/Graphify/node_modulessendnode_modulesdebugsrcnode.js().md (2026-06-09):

---
source_file: ".obsidian/plugins/obsidian-local-rest-api/main.js"
type: "code"
community: "Obsidian REST API Routes"
location: "L42422"
tags:
  - graphify/code
  - graphify/EXTRACTED
  - community/Obsidian_REST_API_Routes
---

# "node_modules/send/node_modules/debug/src/node.js"()

## Connections
- [[main.js]] - `contains` [EXTRACTED]

#graphify/code #graphify/EXTRACTED #community/Obsidian_REST_API_Routes

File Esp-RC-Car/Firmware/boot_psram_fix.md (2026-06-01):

---
tags: [debug, boot, psram, spiram, fix]
---

# Boot Error: PSRAM Abort

## Symptom

```
E (563) quad_psram: PSRAM ID read error: 0x00ffffff, PSRAM chip not found
E (566) cpu_start: Failed to init external RAM!
abort() was called at PC 0x40376cdf
```

Zusätzlich: Factory-Partition corrupt (`invalid segment length 0x5f6f6970` = "pio" ASCII → altes PlatformIO-Binary). Boot fällt korrekt auf `app0` (OTA) zurück, aber crasht dort wegen PSRAM.

## Ursache

`sdkconfig.defaults` hatte `CONFIG_SPIRAM_MODE_QUAD=y` (ESP-IDF Default).
Board ist **ESP32-S3 N16R8** → PSRAM ist **OPI** (Octal SPI), nicht Quad.
Falscher Modus → ID-Read liefert `0x00ffffff` → `abort()`.

| Config | Alt (falsch) | Neu (fix) |
|---|---|---|
| `CONFIG_SPIRAM_SUPPORT=y` | ✅ (alter Name) | entfernt |
| `CONFIG_ESP32S3_SPIRAM_SUPPORT=y` | ✅ (alter Name) | entfernt |
| `CONFIG_SPIRAM=y` | — | ✅ (neuer Name) |
| `CONFIG_SPIRAM_MODE_QUAD=y` | ✅ (falsch) | — |
| `CONFIG_SPIRAM_MODE_OCT=y` | — | ✅ (fix) |

## Fix

**`sdkconfig.defaults`** geändert:
```diff
-CONFIG_SPIRAM_SUPPORT=y
-CONFIG_ESP32S3_SPIRAM_SUPPORT=y
+CONFIG_SPIRAM=y
+CONFIG_SPIRAM_MODE_OCT=y
```

## Nach dem Fix

1. `sdkconfig.espidf_ota` löschen (oder `pio run -e espidf --target menuconfig`)
2. Neu bauen: `pio run -e espidf`
3. Flashen: `pio run -e espidf --target upload`

> Factory-Partition corrupt ist **unkritisch** — Boot-ROM fällt automatisch auf `app0` zurück. Kann mit `pio run -e espidf_factory --target upload` gefixt werden.

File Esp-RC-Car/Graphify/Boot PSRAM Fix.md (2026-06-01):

---
source_file: "Esp-RC-Car/Firmware/boot_psram_fix.md"
type: "document"
community: "Community None"
tags:
  - graphify/document
  - graphify/INFERRED
  - community/Community_None
---

# Boot PSRAM Fix

## Connections
- [[SPIRAM OCT Mode Fix]] - `rationale_for` [INFERRED]

#graphify/document #graphify/INFERRED #community/Community_None

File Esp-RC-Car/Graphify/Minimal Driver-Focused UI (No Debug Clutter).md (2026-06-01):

---
source_file: "App/AppWithoutDev.png"
type: "concept"
community: "Community None"
tags:
  - graphify/concept
  - graphify/INFERRED
  - community/Community_None
---

# Minimal Driver-Focused UI (No Debug Clutter)

## Connections
- [[Clean Dual-Joystick User Interface Layout]] - `conceptually_related_to` [INFERRED]
- [[Developer Panel Expand Chevron (Hidden State)]] - `rationale_for` [INFERRED]

#graphify/concept #graphify/INFERRED #community/Community_None

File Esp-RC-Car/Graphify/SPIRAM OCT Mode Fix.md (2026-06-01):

---
source_file: "Esp-RC-Car/Firmware/boot_psram_fix.md"
type: "rationale"
community: "Community None"
tags:
  - graphify/rationale
  - graphify/INFERRED
  - community/Community_None
---

# SPIRAM OCT Mode Fix

## Connections
- [[Boot PSRAM Fix]] - `rationale_for` [INFERRED]

#graphify/rationale #graphify/INFERRED #community/Community_None

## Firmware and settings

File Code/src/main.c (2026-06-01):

#include <stdio.h>
#include "nvs_flash.h"
#include "esp_netif.h"
#include "esp_event.h"
#include "esp_log.h"
#include "esp_ota_ops.h"
#include "freertos/FreeRTOS.h"
#include "freertos/task.h"
#include "rc_common.h"
#include "rc_system.h"

// Uncomment to run drive test (forward/stop/backward/stop loop) instead of normal app
// #define TEST_DRIVE
// Step diagnostic: cycles 0..5 manually, 800ms each, 50% duty (define STEP_TEST in build_flags)

static const char *TAG = "main";

// Forward declarations (implementiert in jeweiliger Komponente)
void motor_task(void *arg);
void comms_task(void *arg);
void system_task(void *arg);
void bg_task(void *arg);

#ifdef TEST_DRIVE
static void test_drive_task(void *arg)
{
    vTaskDelay(pdMS_TO_TICKS(3000)); // wait for motor init

    Cmd cmd = {.throttle = 0, .steer = 0, .flags = 0};

    ESP_LOGI(TAG, "TEST: forward 50%%");
    cmd.throttle = 500;
    while (1) {
        xQueueOverwrite(cmd_queue, &cmd);
        vTaskDelay(pdMS_TO_TICKS(100));
    }
}
#endif

void app_main(void) {
    esp_err_t ret = nvs_flash_init();
    if (ret == ESP_ERR_NVS_NO_FREE_PAGES ||
        ret == ESP_ERR_NVS_NEW_VERSION_FOUND) {
        ESP_ERROR_CHECK(nvs_flash_erase());
        ret = nvs_flash_init();
    }
    ESP_ERROR_CHECK(ret);

    ESP_ERROR_CHECK(esp_netif_init());
    ESP_ERROR_CHECK(esp_event_loop_create_default());

    rc_common_init();
    esp_ota_mark_app_valid_cancel_rollback();

#if defined(STEP_TEST)
    ESP_LOGI(TAG, "ESP-RC-Car STEP_TEST mode");
    xTaskCreate(motor_task, "motor", 4096, NULL, 10, NULL);
#elif defined(TEST_DRIVE)
    ESP_LOGI(TAG, "ESP-RC-Car TEST_DRIVE mode");
    xTaskCreate(motor_task,     "motor",  4096, NULL, 10, NULL);
    xTaskCreate(test_drive_task,"test",   4096, NULL, 3,  NULL);
#else
    rc_recovery_check();
    rc_settings_load();
    ESP_LOGI(TAG, "ESP-RC-Car (ESP-IDF) starting...");
    xTaskCreate(motor_task,    "motor",    4096, NULL, 10, NULL);
    xTaskCreate(steering_task, "steering", 3072, NULL, 8,  NULL);
    xTaskCreate(comms_task,    "comms",    8192, NULL, 7,  NULL);
    xTaskCreate(system_task,   "system",   6144, NULL, 5,  NULL);
    xTaskCreate(bg_task,       "bg",       6144, NULL, 2,  NULL);
#endif

    vTaskDelete(NULL);
}

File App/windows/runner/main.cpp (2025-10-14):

#include <flutter/dart_project.h>
#include <flutter/flutter_view_controller.h>
#include <windows.h>

#include "flutter_window.h"
#include "utils.h"

int APIENTRY wWinMain(_In_ HINSTANCE instance, _In_opt_ HINSTANCE prev,
                      _In_ wchar_t *command_line, _In_ int show_command) {
  // Attach to console when present (e.g., 'flutter run') or create a
  // new console when running with a debugger.
  if (!::AttachConsole(ATTACH_PARENT_PROCESS) && ::IsDebuggerPresent()) {
    CreateAndAttachConsole();
  }

  // Initialize COM, so that it is available for use in the library and/or
  // plugins.
  ::CoInitializeEx(nullptr, COINIT_APARTMENTTHREADED);

  flutter::DartProject project(L"data");

  std::vector<std::string> command_line_arguments =
      GetCommandLineArguments();

  project.set_dart_entrypoint_arguments(std::move(command_line_arguments));

  FlutterWindow window(project);
  Win32Window::Point origin(10, 10);
  Win32Window::Size size(1280, 720);
  if (!window.Create(L"esp_rc_car", origin, size)) {
    return EXIT_FAILURE;
  }
  window.SetQuitOnClose(true);

  ::MSG msg;
  while (::GetMessage(&msg, nullptr, 0, 0)) {
    ::TranslateMessage(&msg);
    ::DispatchMessage(&msg);
  }

  ::CoUninitialize();
  return EXIT_SUCCESS;
}

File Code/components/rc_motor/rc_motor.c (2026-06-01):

#include "rc_motor.h"
#include "drv8323.h"
#include "driver/ledc.h"
#include "freertos/task.h"
#include "freertos/queue.h"
#include "freertos/event_groups.h"
#include "esp_log.h"
#include "esp_timer.h"

static const char *TAG = "motor";

static const ledc_channel_t CH[6] = {
    LEDC_CHANNEL_0, LEDC_CHANNEL_1,
    LEDC_CHANNEL_2, LEDC_CHANNEL_3,
    LEDC_CHANNEL_4, LEDC_CHANNEL_5,
};

static const gpio_num_t PINS[6] = {
    PIN_INHA, PIN_INLA,
    PIN_INHB, PIN_INLB,
    PIN_INHC, PIN_INLC,
};

// CH: INH_A=0 INL_A=1 INH_B=2 INL_B=3 INH_C=4 INL_C=5
// Motor B/C physically swapped — driver C drives motor B and vice versa
static const int STEP_INH[6] = { 0, 0, 4, 4, 2, 2 };
static const int STEP_INL[6] = { 5, 3, 3, 1, 1, 5 };

static void ledc_init(void)
{
    // GPIO3 is a strapping pin — force-reset before LEDC claims it
    gpio_reset_pin(GPIO_NUM_3);

    ledc_timer_config_t timer = {
        .speed_mode      = LEDC_LOW_SPEED_MODE,
        .duty_resolution = PWM_BITS,
        .timer_num       = LEDC_TIMER_0,
        .freq_hz         = PWM_FREQ_HZ,
        .clk_cfg         = LEDC_AUTO_CLK,
    };
    ledc_timer_config(&timer);

    ledc_channel_config_t ch = {
        .speed_mode = LEDC_LOW_SPEED_MODE,
        .timer_sel  = LEDC_TIMER_0,
        .intr_type  = LEDC_INTR_DISABLE,
        .duty       = 0,
        .hpoint     = 0,
    };
    for (int i = 0; i < 6; i++) {
        ch.channel  = CH[i];
        ch.gpio_num = PINS[i];
        ledc_channel_config(&ch);
    }
}

static void set_duty(ledc_channel_t ch, uint32_t duty)
{
    ledc_set_duty(LEDC_LOW_SPEED_MODE, ch, duty);
    ledc_update_duty(LEDC_LOW_SPEED_MODE, ch);
}

static void all_off(void)
{
    for (int i = 0; i < 6; i++) set_duty(CH[i], 0);
}

static void bootstrap_precharge(void)
{
    set_duty(CH[1], PWM_DUTY_MAX);
    set_duty(CH[3], PWM_DUTY_MAX);
    set_duty(CH[5], PWM_DUTY_MAX);
    vTaskDelay(pdMS_TO_TICKS(5));
    all_off();
    vTaskDelay(pdMS_TO_TICKS(1));
}

static void commutation_delay(uint32_t period_us)
{
    uint64_t deadline = esp_timer_get_time() + period_us;
    while (1) {
        uint64_t now = esp_timer_get_time();
        if (now >= deadline) break;
        if (deadline - now >= 2000)
            vTaskDelay(1);
        else
            taskYIELD();
    }
}

static void apply_step(int step, uint32_t duty)
{
    all_off();
    set_duty(CH[STEP_INH[step]], duty);
    set_duty(CH[STEP_INL[step]], PWM_DUTY_MAX);
}

void motor_task(void *arg)
{
    DRV8323 drv;

#ifdef SPI_TEST_ONLY
    drv8323_init(&drv, PIN_DRV_CS, PIN_DRV_EN, PIN_DRV_FAULT,
                 PIN_DRV_SCLK, PIN_DRV_MISO, PIN_DRV_MOSI);
    while (1) {
        ESP_LOGI(TAG, "FAULT=%03X VGS=%03X",
                 drv8323_read_reg(&drv, ADR_FAULT_STAT),
                 drv8323_read_reg(&drv, ADR_VGS_STAT));
        vTaskDelay(pdMS_TO_TICKS(2000));
    }
#endif

    ledc_init();
    drv8323_init(&drv, PIN_DRV_CS, PIN_DRV_EN, PIN_DRV_FAULT,
                 PIN_DRV_SCLK, PIN_DRV_MISO, PIN_DRV_MOSI);
    all_off();

#ifdef STEP_TEST
    bootstrap_precharge();
    uint32_t test_duty = PWM_DUTY_MAX / 10;
    while (1) {
        for (int s = 0; s < 6; s++) {
            ESP_LOGI(TAG, "STEP %d  INH=%d INL=%d", s, STEP_INH[s], STEP_INL[s]);
            apply_step(s, test_duty);
            vTaskDelay(pdMS_TO_TICKS(3000));
            if (drv8323_has_fault(&drv)) {
                ESP_LOGE(TAG, "FAULT step=%d: 0x%03X 0x%03X", s,
                         drv8323_read_fault1(&drv), drv8323_read_fault2(&drv));
                drv8323_clear_faults(&drv);
            }
        }
    }
#endif

    if (drv8323_has_fault(&drv)) {
        ESP_LOGE(TAG, "Startup fault: 0x%03X 0x%03X",
                 drv8323_read_fault1(&drv), drv8323_read_fault2(&drv));
        vTaskDelete(NULL);
        return;
    }

    bootstrap_precharge();

    int      step          = 0;
    int8_t   direction     = 1;
    int8_t   last_dir      = 0;
    uint32_t duty          = 0;
    uint32_t period_us     = RAMP_START_US;
    int      fault_counter = 0;
    Cmd      cmd           = { 0 };

    while (1) {
        xQueuePeek(cmd_queue, &cmd, 0);

        if (xEventGroupGetBits(rc_events) & SAFE_MODE_BIT) {
            all_off();
            vTaskSuspend(NULL);
            continue;
        }

        int16_t throttle     = cmd.throttle;
        int     abs_throttle = throttle < 0 ? -throttle : throttle;

        if (throttle == 0) {
            all_off();
            period_us = RAMP_START_US;
            last_dir  = 0;
            step      = 0;
            vTaskDelay(pdMS_TO_TICKS(10));
            continue;
        }

        int8_t new_dir = throttle > 0 ? 1 : -1;

        if (new_dir != last_dir) {
            all_off();
            direction = new_dir;
            last_dir  = new_dir;
            period_us = RAMP_START_US;
            apply_step(0, PWM_DUTY_MAX * 4 / 10);
            vTaskDelay(pdMS_TO_TICKS(800));
            step = 0;
        }

        // Proportional duty: scaled by throttle. Floor only applied during ramp-up
        // so the field can keep rotating before back-EMF stabilises.
        uint32_t target_duty = (uint32_t)abs_throttle * PWM_DUTY_MAX / 1000;

        if (target_duty < PWM_DUTY_MAX * 80 / 100) target_duty = PWM_DUTY_MAX * 80 / 100;

        if (period_us > RAMP_END_US) {
            duty = target_duty * RAMP_END_US / period_us;
        } else {
            duty = target_duty;
        }

        apply_step(step, duty);
        step = (step + direction + 6) % 6;

        commutation_delay(period_us);

        if (period_us > RAMP_END_US) {
            period_us -= RAMP_STEP_US;
            if (period_us < RAMP_END_US) period_us = RAMP_END_US;
        }

        if (++fault_counter >= FAULT_CHECK_STEPS) {
            fault_counter = 0;
            if (drv8323_has_fault(&drv)) {
                ESP_LOGE(TAG, "Fault: 0x%03X 0x%03X",
                         drv8323_read_fault1(&drv), drv8323_read_fault2(&drv));
                all_off();
                vTaskDelay(pdMS_TO_TICKS(200));
                drv8323_clear_faults(&drv);
                bootstrap_precharge();
                period_us = RAMP_START_US;
            }
        }
    }
}

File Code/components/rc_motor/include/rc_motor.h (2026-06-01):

#pragma once
#include "rc_common.h"
#include "driver/ledc.h"

#define PWM_FREQ_HZ           20000
#define PWM_BITS              LEDC_TIMER_10_BIT
#define PWM_DUTY_MAX          1023

#define RAMP_START_US    5000   // 5ms start: duty=20% → enough to overcome static friction
#define RAMP_END_US      4000   // 4ms end — slower field, less wheel speed
#define RAMP_STEP_US      250   // ~22 steps total ramp
#define FAULT_CHECK_STEPS 50

void motor_task(void *arg);

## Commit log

2025-09-12 Delete PCB/ESP-RC-Car directory
    delete extra pcb project
    [ESP-RC-Car.PcbDoc, ESP-RC-Car.PrjPcb, ESP-RC-Car.SchDoc]
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2025-10-15 Refactor code structure for improved readability and maintainability
    [ESP-RC-Car.PcbDoc, ESP-RC-Car.PrjPcb, ESP-RC-Car.SchDoc]
2025-10-15 updated app and schematic
    [ESP-RC-Car.PcbDoc, ESP-RC-Car.SchDoc]
2025-10-19 pcb fertig glaub
    [ESP-RC-Car.PrjPcb, ESP-RC-Car.SchDoc]
2025-10-20 chassi V8 just small improvements
    [Chassi V8.obj]
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2025-10-23 repaired errors
    [ESP-RC-Car.SchDoc]
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2025-10-24 removed webserver
    [ESP-RC-Car.PcbDoc]
2025-10-24 Create Chassi V8.stl
    [Chassi V8.stl]
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2025-11-08 feat: Implement connection service and UI for ESP RC Car
    - Added ConnectionService to manage WebSocket connections and device discovery.
    - Implemented UDP and TCP discovery methods for finding devices.
    - Created DevPanel UI for connecting to WebSocket and displaying connection status.
    - Added GamepadStatus widget to show gamepad connection and throttle status.
    - Introduced EdgeStickyJoystick for joystick control with adjustable sensitivity.
    - Updated pubspec.yaml and pubspec.lock to include new dependencies.
2025-11-09 feat: Add local network usage description and enhance connection service with last known URL handling and controller integration
    [ESP-RC-Car.SchDoc]
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2025-11-10 feat: Improve TCP discovery logging with detailed messages for subnet checks and probe results
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2025-12-04 Enable USB CDC on boot and update PCB files
    Added build flags to enable USB CDC on boot in platformio.ini for improved USB functionality. Updated PCB and schematic files, likely reflecting hardware or layout changes for the ESP-RC-Car project.
    [ESP-RC-Car.SchDoc]
2025-12-04 Document issues with PCB components
    Added note about USB PD IC pin connection issue.
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2026-01-09 Add USB PD support and update PCB project files
    Added usbpd.cpp for STUSB4500 USB Power Delivery control and updated platformio.ini to include SparkFun STUSB4500 library. Modified PCB project files to reference new fixed board files and updated generated document paths. Removed the README from the include directory.
    [ESP-RC-Car.PrjPcb, ESP-RC-Car.SchDoc]
2026-01-16 Update PCB and schematic files, rename usbpd.cpp
    Renamed usbpd.cpp to usbpd.cpp.old and removed an extraneous character from setup(). Updated PCB and schematic files (ESP-RC-Car.PcbDoc, ESP-RC-Car.SchDoc, ESP-RC-Car.fixed.PcbDoc) with new changes.
    [ESP-RC-Car.SchDoc]
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2026-03-16 begin rebuilding pcb
    [ESP-RC-Car.PrjPcb, ESP-RC-Car.SchDoc]
2026-03-18 Add DRV8323 driver and integrate into main
    Introduce DRV8323 driver (drv8323.h/cpp) providing 16-bit SPI frame transfers, register read/write, fault queries and hardware fault clear via EN pulse. Integrate the driver in main.cpp: add pin defi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
2026-03-19 Refactor battery monitoring to use percentage instead of voltage and update broadcast format
2026-03-27 Add esp32FOTA-based FOTA support
    Integrate esp32FOTA for over-the-air updates via GitHub releases. Adds a firmware manifest (Code/fota/firmware.json) with release URLs, adds esp32FOTA dependency to platformio.ini, and integrates FOTA into main.cpp: include header, define FOTA config macros (type, version, manifest URL, check interval), instantiate espFOTA, set manifest URL on WiFi connect, and perform periodic HTTP checks/OTA while connected. Update checks are disabled if the manifest URL is empty; initial check is scheduled shortly after connecting.
    [main.cpp]
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2026-03-29 Refactor device settings management: add load and save functions for persistent configuration
2026-03-29 Fix loadSettings to use non-volatile storage mode for device configuration
    [main.cpp]
2026-03-29 Enhance settings management: add ADC calibration factor and update UI for OTA interval and other settings
2026-03-29 Refactor settings management: replace dropdowns with checkboxes for OTA and steering invert options
    [main.cpp]
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2026-04-01 Add core functionality for ESP-RC-Car
    - Implemented HTTP API for captive portal and network management in rc_httpapi.h and rc_httpapi.cpp.
    - Added LED control functionality in rc_led.cpp and rc_led.h, allowing LED blinking based on throttle input.
    - Developed motor control logic in rc_motor.cpp and rc_motor.h, including phase application and fault checking.
    - Created network management system in rc_network.cpp and rc_network.h for WiFi scanning, saving, and connecting.
    - Integrated OTA update mechanism in rc_ota.cpp and rc_ota.h for firmware updates via GitHub.
    - Established pin definitions in rc_pins.h for hardware connections.
    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
2026-04-03 feat: Enhance OTA and Console Functionality
    - Added ArduinoOTA support in rc_ota.h for improved OTA update management.
    - Refactored rc_serial.cpp to utilize a new RCConsole class for dual output to Serial and WebSocket terminal.
    - Updated command handling to support new commands and improved logging functionality.
    - Introduced rc_console.h and rc_console.cpp for centralized console output management.
    - Modified rc_settings to include a new setting for always starting the config panel.
    - Enhanced rc_websocket to handle terminal commands received via WebSocket.
    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
2026-04-07 feat: Implement factory recovery firmware and stability features
    [partitions.csv]
2026-04-09 Update PCB DocumentPath to user 'Super'
    Replace hardcoded Windows user path in PCB project with the new user directory. The .PrjPcb now references C:\Users\Super\... instead of C:\Users\Mirko\... for two Output Configuration DocumentPath entries, and the PCB document (.PcbDoc) binary was updated accordingly.
    [ESP-RC-Car.PcbDoc, ESP-RC-Car.PrjPcb]
2026-04-10 feat: Update partition sizes and configurations for improved memory management
    [partitions.csv]
2026-04-13 refactor(motor): replace diagnostic constants with commutation timing
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2026-04-13 feat(motor): update setup to attach LEDC on all 3 phases and init state machine
2026-04-13 feat(motor): implement 6-step trapezoidal commutation with ramp-up and direction reversal
2026-04-16 feat(fs): change partition subtype from spiffs to littlefs
    [partitions.csv]
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2026-05-08 motor connected. test run required
    [lib.SchLib]
2026-05-08 fixed a bug where every upload just gets dumped
    [main.c, rc_motor.h]
2026-05-17 car runs just need a little bit of fine tuning between throttle and duty. right now it is jist a test run no manual controlling
2026-05-20 fix(rc): restore app→motor/servo control path
    - rc_comms: stamp s_last_cmd_tick in both WS handlers so failsafe no
    longer overwrites cmd_queue with zero on every poll
    - rc_motor: peek cmd_queue instead of receive so steering task can
    read the same Cmd; drop 60% duty floor → 20% only during ramp-up
    - rc_system: split steering into its own 50 Hz task so 1 s ADC
    oversampling no longer stalls the servo
    - main: spawn steering_task at priority 8
    - app: emergency-stop button, exponential reconnect backoff,
    EMA filter formula fix, send-only-when-connected guard
    [main.c, rc_comms.c, rc_motor.c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]
2026-05-20 chore: misc updates + ignore Claude artefacts
    - .gitignore: add CLAUDE.md and graphify-out/
    - untrack .claude/settings.local.json
    - KiCad project + backup updates
    - iOS AppDelegate, release workflow tweaks
    - sdkconfig drift, dependencies.lock update
    - add Graphify notes
    [ESP-RC-Car.kicad_pcb]
2026-05-20 ci: switch esp_littlefs to Espressif registry, drop stale lock
    Git-source dep with submodule produced unstable component hash → CI
    hash-mismatch fail. Use joltwallet/littlefs from registry for stable
    hash. Lock will regenerate per build.
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2026-05-29 protocoll last check needed
    [ESP-RC-Car-OLDPCB.SchDoc, ESP-RC-Car_NEW.PcbDoc, ESP-RC-Car_NEW.SchDoc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]
2026-05-31 Move PCB files and rename protocol doc
    Relocate Altium PCB/schematic files into PCB/PCBCopyProtokoll (preserving content). Rename PROTOKOLL_FINAL.docx to ESPRCCarProtokollHaunoldDillinger.docx, delete obsolete PROTOKOLL.docx, and add a ne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
    [ESP-RC-Car-OLDPCB.SchDoc, ESP-RC-Car_NEW.PcbDoc, ESP-RC-Car_NEW.SchDoc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]
2026-05-31 Rewrite release workflow to multi-target CI
    Replace single firmware release job with a multi-job release workflow that builds firmware (PlatformIO + LittleFS), Android APK, and iOS IPA, and uploads artifacts/releases for each target. Adds workflow_dispatch trigger for manual runs, injects release tag as FOTA_CURRENT_VERSION into platformio.ini, switches to PlatformIO for ESP32 build, and handles iOS signing via repository secrets with a fallback unsigned IPA. Also updates artifact paths and upload steps. Remove temporary ~$PRCCarProtokollHaunoldDillinger.docx file.
2026-05-31 Use esp_driver_* components instead of 'driver'
    Replace the generic 'driver' dependency with explicit esp_driver_* components in CMakeLists to make driver dependencies granular and explicit.
    Updates:
    - rc_common: added esp_driver_gpio
    - rc_comms: removed driver, added esp_driver_gpio
    - rc_motor: replaced driver with esp_driver_gpio, esp_driver_spi, esp_driver_ledc
    - rc_system: removed driver, added esp_driver_gpio and esp_driver_ledc
    This clarifies which driver modules each component needs and avoids depending on a monolithic driver package.
2026-05-31 Use WIFI_BW20 and add FreeRTOS include
    Replace WIFI_BW_HT20 with WIFI_BW20 for both AP and STA to match the updated ESP-IDF bandwidth enum. Add #include <freertos/FreeRTOS.h> in drv8323.c so FreeRTOS types/macros used by task APIs are available.
    [drv8323.c, rc_comms.c]
2026-06-01 Add in-app updater and CI Android signing
    Introduce an in-app update flow and CI signing for Android. Adds UpdateService to query GitHub Releases for a newer EspRCCar.apk, download the APK with progress, and open the installer (uses http, package_info_plus, path_provider, open_filex). Integrates a DevPanel button (Android-only) to check/download/install updates and shows progress/errors. CI: workflow now decodes a base64 keystore from secrets into android/key.properties, uses the release tag to set build-name, and builds the APK. Android project: read key.properties in build.gradle.kts to configure release signing (falls back to debug locally), add .p12 to .gitignore, and request REQUEST_INS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
2026-06-02 Aufräumen
    [ESP-RC-Car.kicad_pcb, lib.SchLib]
2026-06-04 präsi
    [verbindung v1.blend, verbindung v1.stl]
